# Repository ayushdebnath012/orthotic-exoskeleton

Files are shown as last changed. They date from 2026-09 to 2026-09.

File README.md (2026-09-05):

# Orthotic Exoskeleton

Design and analysis workspace for **ExoEskeleto**, a lower-limb orthotic exoskeleton. This repository brings together CAD models, manufacturing drawings, gait animations, Euler–Lagrange torque analysis, component spreadsheets, and research documents.

The current actuator-sizing study uses a **passive hip with powered knee and ankle joints**, following the updated manufacturing drawing. Research documents also explore vision-language-action (VLA) assistance and fall-risk modelling.

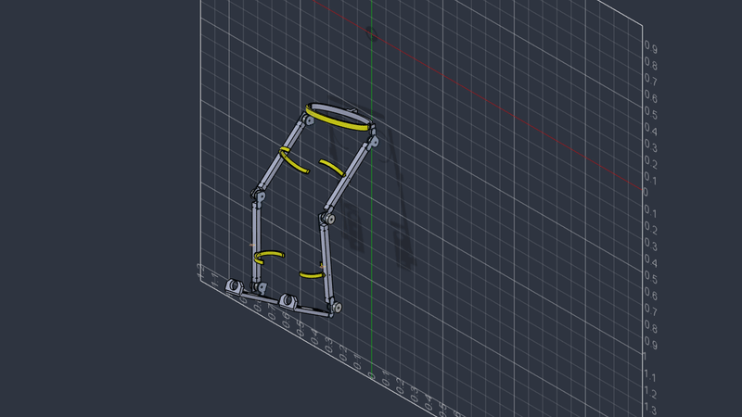
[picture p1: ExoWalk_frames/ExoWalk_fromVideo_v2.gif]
Exoskeleton gait animation


## Start here

- [Updated manufacturing drawing](ExoEskeleto_Manufacturing_Drawing%20%281%29.pdf) — hardware geometry and actuator layout.
- [Torque analysis, version 2](Motor_Torque_Analysis_ExoEskeleto_v2.md) — model, assumptions, load cases, and actuator-sizing rationale.
- [Torque analysis PDF](output/pdf/Motor_Torque_Analysis_ExoEskeleto_v2.pdf) — shareable report.
- [Bill of materials](Low_Cost_Exoskeleton_VLA_BOM_VALIDATED.xlsx) and [shopping list with screenshots](Exoskeleton_Shopping_List_with_Screenshots.xlsx) — component planning.

## Repository guide

| File or folder | Contents |
| --- | --- |
| [ExoEskeleto_final.step](ExoEskeleto_final.step) | Neutral-format assembly geometry |
| [Exoskeleton.stp.SLDPRT](Exoskeleton.stp.SLDPRT) | SolidWorks part model |
| [MOSAIC_HIP_SOLIDWORKS/](MOSAIC_HIP_SOLIDWORKS/) | Pelvic plate and hip-module part files |
| [Lagrange_Euler_Torque_Power.py](Lagrange_Euler_Torque_Power.py) | Three-link inverse dynamics, torque/power calculations, and sizing outputs |
| [ExoWalk_frames/](ExoWalk_frames/) | Joint-angle JSON data, rendered frames, GIFs, and videos |
| [exo selection animations/](exo%20selection%20animations/) | Selected walking and running animations |
| [output/torque_analysis/](output/torque_analysis/) | Saved CSV and JSON results plus torque and sizing plots |
| [output/pdf/](output/pdf/) | Version 1 and version 2 analysis reports |
| `Motor_Torque_Analysis_ExoEskeleto_v1.*` / `v2.*` | Analysis documents and available source formats |
| [ExoVLA_WM_paper.pdf](ExoVLA_WM_paper.pdf), [aegis.pdf](aegis.pdf) | Research context for assistance and control |

The version 2 report follows the updated manufacturing drawing and supersedes the earlier actuator-sizing assumptions. `ExoEskeleto_final.SLDASM` is currently an empty file; use the STEP geometry and available part files when inspecting the design.

## Run the torque analysis

Use Python 3.10 or newer with NumPy, SciPy, and Matplotlib. Run the commands from the repository root so the default gait-data path resolves correctly.

```bash
git clone https://github.com/ayushdebnath012/orthotic-exoskeleton.git
cd orthotic-exoskeleton
python3 -m pip install numpy scipy matplotlib

# Print model checks, gait results, and actuator ratings.
python3 Lagrange_Euler_Torque_Power.py

# Also generate CSV, JSON, and PNG artifacts.
python3 Lagrange_Euler_Torque_Power.py --write
```

By default, `--write` saves these files to `output/torque_analysis/`, replacing existing results with the same names:

- `euler_lagrange_gait_results.csv`
- `euler_lagrange_summary.json`
- `gait_joint_torque.png`
- `support_motor_sizing.png`

For a separate run with a different user mass:

```bash
python3 Lagrange_Euler_Torque_Power.py \
  --user-mass 70 \
  --write \
  --output-dir output/torque_analysis_70kg
```

Use `python3 Lagrange_Euler_Torque_Power.py --help` to see options for frame mass, moving-link masses, gait input, cycle time, support load, centre-of-pressure offset, and engineering factor. Matplotlib uses a non-interactive backend, so plot generation does not require a display.

## Model and sizing baseline

The analysis represents one leg as three rigid links in the sagittal plane. It evaluates a swing phase using the supplied CAD gait and a bent-knee support/sit-to-stand load case.

| Default parameter | Value |
| --- | --- |
| User mass | 80 kg |
| Frame mass | 6.49 kg |
| Thigh / shank / foot lengths | 0.400 / 0.420 / 0.260 m |
| Gait cycle | 2.4 s |
| Vertical support per leg | 0.60 × combined user and frame weight |
| Centre-of-pressure offset | 0.060 m forward of the ankle |
| Engineering factor | 1.50 |

The version 2 study selects these provisional targets **per side**, at the joint output:

| Joint | Actuation | Continuous torque target | Peak torque target | Reduction ratio |
| --- | --- | ---: | ---: | ---: |
| Hip | Passive | — | — | — |
| Knee | Powered | 60 N·m | 120 N·m | 80:1 |
| Ankle | Powered | 30 N·m | 60 N·m | 60:1 |

The passive hip still carries a reaction moment. These targets are engineering sizing results, not measured actuator performance. See the [full report](Motor_Torque_Analysis_ExoEskeleto_v2.md) for load-case calculations and motor-side torque estimates.

## Status and assumptions

This repository is a design and engineering study. The model uses estimated body-segment properties and an allocated distribution of frame mass. Measured ground-reaction-force histories, exported CAD joint zeros, motor/gearbox masses, rotor inertia, friction, backlash, and efficiency maps are not supplied. The analysis is not a human-use safety certification.

The repository includes existing research and project documents alongside the analysis. No repository-wide license has been specified.

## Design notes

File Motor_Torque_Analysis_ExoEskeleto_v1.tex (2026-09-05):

\documentclass[11pt,a4paper]{article}

\usepackage[a4paper,top=20mm,bottom=20mm,left=19mm,right=19mm,headheight=15pt]{geometry}
\usepackage[T1]{fontenc}
\usepackage{lmodern}
\usepackage{microtype}
\usepackage{graphicx}
\usepackage{booktabs}
\usepackage{tabularx}
\usepackage{array}
\usepackage{longtable}
\usepackage{amsmath}
\usepackage{enumitem}
\usepackage{xcolor}
\usepackage{fancyhdr}
\usepackage{titlesec}
\usepackage{hyperref}
\usepackage{lastpage}
\usepackage{caption}
\usepackage{float}

\definecolor{Navy}{HTML}{17324D}
\definecolor{Teal}{HTML}{167C80}
\definecolor{PaleTeal}{HTML}{E8F3F3}
\definecolor{PaleBlue}{HTML}{EDF2F7}
\definecolor{Warm}{HTML}{F6F1E8}
\definecolor{Ink}{HTML}{25313C}
\definecolor{Muted}{HTML}{647482}
\definecolor{Rule}{HTML}{CCD6DD}

\hypersetup{
  colorlinks=true,
  linkcolor=Navy,
  urlcolor=Teal,
  pdftitle={Preliminary Motor and Joint-Torque Analysis - ExoEskeleto v1},
  pdfauthor={Engineering analysis prepared from ExoEskeleto Drawing v1}
}

\color{Ink}
\setlength{\parindent}{0pt}
\setlength{\parskip}{5.5pt}
\setlist[itemize]{leftmargin=5mm,itemsep=2pt,topsep=3pt}
\setlist[enumerate]{leftmargin=6mm,itemsep=2pt,topsep=3pt}
\renewcommand{\arraystretch}{1.18}
\captionsetup{font=small,labelfont={bf,color=Navy}}

\titleformat{\section}
  {\Large\bfseries\color{Navy}}
  {\thesection}{0.65em}{}
  [\vspace{-3pt}\color{Teal}\titlerule]
\titleformat{\subsection}
  {\large\bfseries\color{Navy}}
  {\thesubsection}{0.55em}{}
\titleformat{\subsubsection}
  {\normalsize\bfseries\color{Teal}}
  {\thesubsubsection}{0.5em}{}
\titlespacing*{\section}{0pt}{13pt}{7pt}
\titlespacing*{\subsection}{0pt}{10pt}{4pt}
\titlespacing*{\subsubsection}{0pt}{8pt}{3pt}

\pagestyle{fancy}
\fancyhf{}
\fancyfoot[L]{\small\color{Muted}Preliminary engineering analysis}
\fancyfoot[R]{\small\color{Muted}Page \thepage\ of \pageref*{LastPage}}
\renewcommand{\headrulewidth}{0pt}
\renewcommand{\footrulewidth}{0pt}
\fancypagestyle{plain}{%
  \fancyhf{}
  \fancyfoot[L]{\small\color{Muted}Preliminary engineering analysis}
  \fancyfoot[R]{\small\color{Muted}Page \thepage\ of \pageref*{LastPage}}
  \renewcommand{\headrulewidth}{0pt}
  \renewcommand{\footrulewidth}{0pt}
}

\newcommand{\unit}[1]{\ensuremath{\,\mathrm{#1}}}
\newcommand{\Nm}{\unit{N\,m}}
\newcommand{\highlightbox}[2]{%
  \begingroup
  \setlength{\fboxsep}{8pt}%
  \noindent\colorbox{#1}{\parbox{\dimexpr\linewidth-2\fboxsep\relax}{#2}}%
  \endgroup
}
\newcommand{\ratingcard}[3]{%
  \begin{minipage}[t]{0.30\textwidth}
    \colorbox{PaleTeal}{\parbox[c][27mm][c]{\dimexpr\linewidth-2\fboxsep\relax}{
      \centering\color{Navy}\bfseries #1\\[2pt]
      {\Large\color{Teal}#2}\\[-1pt]
      {\scriptsize\color{Muted}#3}
    }}
  \end{minipage}%
}

\begin{document}

\begin{titlepage}
  \thispagestyle{empty}
  \vspace*{-5mm}
  {\color{Teal}\rule{\linewidth}{2.2mm}}\\[8mm]
  {\small\bfseries\color{Teal}\MakeUppercase{Preliminary engineering report}}\\[5mm]
  {\fontsize{28}{32}\selectfont\bfseries\color{Navy}
    Motor and Joint-Torque Analysis}\\[2mm]
  {\Large\color{Muted}ExoEskeleto Drawing v1}\\[4mm]
  {\color{Rule}\rule{\linewidth}{0.8pt}}

  \begin{center}
    
  \end{center}

  \vspace{-2mm}
  \begin{center}
    \ratingcard{HIP}{120--150\Nm}{peak output, each side}\hfill
    \ratingcard{KNEE}{80--110\Nm}{peak output, each side}\hfill
    \ratingcard{ANKLE}{120--150\Nm}{peak output, each side}
  \end{center}
  \vspace{5mm}

  \begin{tabularx}{\linewidth}{@{}>{\bfseries\color{Navy}}p{35mm}X@{}}
    Source drawing & \texttt{ExoEskeleto Drawing v1.pdf}, 17 sheets \\
    Drawing date & 13 July 2026 \\
    Reference user & 80 kg \\
    Report status & Preliminary sizing; not approved for human testing \\
  \end{tabularx}

  \vfill
  {\small\color{Muted}Prepared from the geometry and bill of materials supplied in the source drawing.}
\end{titlepage}

\pagenumbering{arabic}

\highlightbox{Warm}{%
  \textbf{Scope and safety limitation.} This report is a first-pass actuator-sizing study based on the drawing and explicitly stated assumptions. It is not a final design approval or safety certification. Complete CAD mass-property extraction, multibody simulation, structural FEA, brake validation, thermal/electrical analysis, and controlled bench testing are required before testing on a person.
}

\tableofcontents
\vspace{4mm}

\section{Executive summary}

The 17-sheet drawing establishes the overall exoskeleton arrangement and principal link geometry. It does not define rotary motors, gearboxes, rated joint torques, component mass properties, actuator moment arms, gait profiles, or an assistance target. The bill of materials instead identifies seven electromagnets and eleven magnetic laminations or plates.

For a reference 80 kg user and a full lower-limb support envelope, the recommended preliminary output-side ratings are shown in Table~\ref{tab:ratings}. Six powered flexion/extension joints are implied if both hip, knee, and ankle joints are actuated.

Applying the Lagrange-Euler equation to the report's three-link reference model gives, for the stated horizontal dynamic example, $60.21\Nm$ and 90.31 W at the hip, $17.99\Nm$ and 35.98 W at the knee, and $2.54\Nm$ and 6.35 W at the ankle. These are unfactored swing-phase values for human-segment mass only; they exclude exoskeleton mass and ground-reaction force.

\begin{table}[H]
\centering
\caption{Preliminary joint-output design envelope, each side.}
\label{tab:ratings}
\small
\begin{tabularx}{\linewidth}{@{}>{\raggedright\arraybackslash}p{32mm}
  >{\centering\arraybackslash}p{24mm}
  >{\centering\arraybackslash}p{24mm}
  >{\centering\arraybackslash}p{19mm}X@{}}
\toprule
\textbf{Joint} & \textbf{Continuous torque} & \textbf{Peak torque} & \textbf{Output speed} & \textbf{Approximate actuator class} \\
\midrule
Hip flexion/extension & 45--60\Nm & 120--150\Nm & 0--3 rad/s & 300--500 W BLDC with low-backlash reducer \\
Knee flexion/extension & 30--45\Nm & 80--110\Nm & 0--4 rad/s & 250--400 W BLDC with low-backlash reducer \\
Ankle plantar/dorsiflexion & 45--60\Nm & 120--150\Nm & 0--5 rad/s & 350--600 W BLDC with reducer or remote transmission \\
\bottomrule
\end{tabularx}
\end{table}

\highlightbox{PaleTeal}{%
  \textbf{Primary design finding.} The electromagnets should be treated as auxiliary locks, clutches, or mode-selection devices unless their force-versus-gap and friction performance are demonstrated. They should not be assumed to replace torque-controlled rotary actuators or certified fail-safe brakes.
}

\section{Drawing basis and observed geometry}

\subsection{Information established by the drawing}

\begin{itemize}
  \item Overall envelope: approximately 1009 mm high, 1009 mm long, and 662 mm wide (sheet 2).
  \item Principal long members: approximately 400--420 mm on the detail sheets.
  \item Several circular joint/interface details: approximately 50 mm outside diameter with 10 mm bores.
  \item Bill of materials: seven \texttt{ELECTROIMAN} units and eleven magnetic laminations or plates.
  \item Listed structural parts are identified as steel.
  \item The assembly appears to comprise bilateral lower-limb links connected to a waist ring and foot/boot interfaces.
\end{itemize}

\subsection{Information not supplied}

The drawing does not provide maximum user mass, payload, part masses, centres of mass, gait cycle, required assistance percentage, motor torque-speed curves, gearbox ratios or efficiencies, bearing friction, joint range, structural steel grade, weld specifications, or electromagnet force data. These omissions prevent an exact CAD-derived actuator calculation.

\section{Reference design case}

The assumptions in Table~\ref{tab:assumptions} provide a transparent first-pass sizing case. Segment masses are anthropometric approximations and exclude exoskeleton hardware.

\begin{table}[H]
\centering
\caption{Reference assumptions used in the calculations.}
\label{tab:assumptions}
\begin{tabularx}{0.88\linewidth}{@{}X>{\raggedleft\arraybackslash}p{59mm}@{}}
\toprule
\textbf{Parameter} & \textbf{Assumption} \\
\midrule
User mass & 80 kg \\
Thigh length & 0.42 m \\
Shank length & 0.40 m \\
Foot COM distance from ankle & 0.13 m \\
One thigh mass & 10.0\% body mass = 8.00 kg \\
One shank mass & 4.65\% body mass = 3.72 kg \\
One foot mass & 1.45\% body mass = 1.16 kg \\
Thigh and shank COM location & 43.3\% of segment length from proximal joint \\
Gravity, $g$ & $9.81\unit{m/s^2}$ \\
Dynamic multiplier & 2.0 \\
Engineering factor after dynamics & 1.5 \\
\bottomrule
\end{tabularx}
\end{table}

The dynamic and engineering factors are included to establish an actuator selection envelope. Final load cases must instead use measured or simulated joint torque histories and include every moving exoskeleton component.

\section{Static gravity calculations}

For a point mass, the gravity moment about a joint is
\begin{equation}
  T = m g r,
\end{equation}
where $r$ is the horizontal distance from the joint axis. Gravity torque is largest when the segment is approximately horizontal.

\subsection{Hip: one leg held horizontal}

\begin{align}
T_{\mathrm{hip}} = g\big[&m_t(0.433L_t)
  + m_s(L_t+0.433L_s) \notag\\
  &+m_f(L_t+L_s+r_f)\big].
\end{align}

For the 80 kg reference user,
\begin{equation}
  \boxed{T_{\mathrm{hip}} = 46.7\Nm}
\end{equation}
for limb self-weight alone. This does not include the exoskeleton links, actuator masses, payload, or ground-reaction effects.

\subsection{Knee: shank and foot held horizontal}

\begin{equation}
T_{\mathrm{knee}} = g\left[m_s(0.433L_s)+m_f(L_s+r_f)\right],
\end{equation}
giving
\begin{equation}
  \boxed{T_{\mathrm{knee}} = 12.3\Nm}.
\end{equation}

\subsection{Ankle: ground-reaction load governs}

Foot self-weight produces only about $1.5\Nm$. This is not the governing ankle case. During standing and walking, ground-reaction force acts at a horizontal offset from the ankle. For the complete 80 kg body load and a 50--120 mm centre-of-pressure offset,
\begin{align}
T_{\mathrm{ankle}}
 &= (80)(9.81)(0.05\text{ to }0.12) \\
 &= \boxed{39\text{ to }94\Nm}.
\end{align}

In symmetric double support, each side may carry approximately half the load. In single support, one side can approach the full value and can exceed it dynamically.

\section{Lagrange-Euler torque and power calculation}

\subsection{Three-link planar model}

Let
\begin{equation}
  \mathbf q = [q_1\ q_2\ q_3]^T
\end{equation}
contain the relative hip, knee, and ankle angles. The pelvis is treated as a fixed base; $q_1$ is measured from the global horizontal, while $q_2$ and $q_3$ are relative angles. Positive rotation is counter-clockwise.

For the three moving segments, the kinetic and potential energies are
\begin{align}
K &= \frac{1}{2}\sum_{i=1}^{3}
  \left(m_i\dot{\mathbf r}_i^T\dot{\mathbf r}_i
  + I_i\omega_i^2\right),\\
V &= \sum_{i=1}^{3}m_i g y_i,
\end{align}
and the Lagrangian is $\mathcal L=K-V$. Applying the requested equation at each joint,
\begin{equation}
  \tau_i=\frac{d}{dt}\left(\frac{\partial\mathcal L}
  {\partial\dot q_i}\right)-\frac{\partial\mathcal L}{\partial q_i},
\end{equation}
gives the manipulator form
\begin{equation}
\boxed{\boldsymbol\tau_{\mathrm{act}}
=\mathbf M(\mathbf q)\ddot{\mathbf q}
+\mathbf C(\mathbf q,\dot{\mathbf q})\dot{\mathbf q}
+\mathbf G(\mathbf q)-\mathbf J_f^T\mathbf F_{\mathrm{ext}}.}
\end{equation}

The final term is essential in stance: $\mathbf F_{\mathrm{ext}}$ is the measured ground-reaction force at the foot and $\mathbf J_f$ is the foot Jacobian. It is set to zero in the numerical swing example because no force history is supplied.

Segment inertias are estimated using $I_i=m_i(k_iL_i)^2$. The radius-of-gyration fractions for thigh, shank, and foot are 0.323, 0.302, and 0.475, respectively. The calculation includes human segment mass only.

\subsection{Numerical input state}

The selected instant is deliberately explicit so that the result can be reproduced or replaced with measured data.

\begin{table}[H]
\centering
\caption{State used for the illustrative Lagrange-Euler calculation.}
\label{tab:lagrange-input}
\begin{tabular}{@{}lccc@{}}
\toprule
\textbf{Quantity} & \textbf{Hip} & \textbf{Knee} & \textbf{Ankle} \\
\midrule
$q_i$ & $0^\circ$ & $0^\circ$ & $0^\circ$ \\
$\dot q_i$ & 1.5 rad/s & 2.0 rad/s & 2.5 rad/s \\
$\ddot q_i$ & $3.0\unit{rad/s^2}$ & $4.0\unit{rad/s^2}$ & $5.0\unit{rad/s^2}$ \\
External foot force & \multicolumn{3}{c}{$\mathbf F_{\mathrm{ext}}=[0\ 0]^T\unit{N}$} \\
\bottomrule
\end{tabular}
\end{table}

At this collinear horizontal configuration,
\begin{equation}
\mathbf M=
\begin{bmatrix}
2.8397 & 1.0382 & 0.1610\\
1.0382 & 0.5094 & 0.0976\\
0.1610 & 0.0976 & 0.0373
\end{bmatrix}\unit{kg\,m^2},
\end{equation}
\begin{equation}
\mathbf G=
\begin{bmatrix}46.7308\\12.3518\\1.4793\end{bmatrix}\Nm,
\qquad
\mathbf C\dot{\mathbf q}=\mathbf 0.
\end{equation}

The Coriolis/centrifugal vector is zero at this particular collinear state because the required sine coupling terms vanish; it is generally non-zero at other postures.

\subsection{Calculated torque and joint power}

Instantaneous joint mechanical power is
\begin{equation}
  \boxed{P_i=\tau_i\dot q_i.}
\end{equation}
Positive power drives the motion; negative power indicates braking or potential regeneration.

\begin{table}[H]
\centering
\caption{Unfactored dynamic result for the state in Table~\ref{tab:lagrange-input}.}
\label{tab:lagrange-result}
\small
\begin{tabular}{@{}lrrrr@{}}
\toprule
\textbf{Joint} & \textbf{Inertial} & \textbf{Gravity} & \textbf{Total torque} & \textbf{Joint power} \\
& \textbf{(N m)} & \textbf{(N m)} & \textbf{(N m)} & \textbf{(W)} \\
\midrule
Hip & 13.477 & 46.731 & \textbf{60.208} & \textbf{90.311} \\
Knee & 5.640 & 12.352 & \textbf{17.992} & \textbf{35.985} \\
Ankle & 1.060 & 1.479 & \textbf{2.539} & \textbf{6.348} \\
\midrule
Total & & & & \textbf{132.644} \\
\bottomrule
\end{tabular}
\end{table}

For example, the first-joint calculation is
\begin{align}
\tau_1 &=
  2.8397(3)+1.0382(4)+0.1610(5)+46.7308 \\
  &=\boxed{60.208\Nm},\\
P_1 &= \tau_1\dot q_1
  =60.208(1.5)=\boxed{90.311\unit{W}}.
\end{align}

If a separate 1.5 engineering factor is applied after this trajectory calculation, the resulting provisional values are 90.31, 26.99, and $3.81\Nm$ for hip, knee, and ankle. The ankle value remains unsuitable for stance sizing because the ground-reaction term is absent.

\subsection{Illustrative gearbox mapping}

Using 80:1 hip and knee reducers, a 60:1 ankle reducer, and 75\% gearbox efficiency gives Table~\ref{tab:motor-map}. Shaft power is joint power divided by gearbox efficiency; electrical input will be higher again after motor and drive losses.

\begin{table}[H]
\centering
\caption{Motor-side result for the illustrative swing state.}
\label{tab:motor-map}
\begin{tabular}{@{}lrrrr@{}}
\toprule
\textbf{Joint} & \textbf{Ratio} & \textbf{Motor torque} & \textbf{Motor speed} & \textbf{Shaft power} \\
& & \textbf{(N m)} & \textbf{(rpm)} & \textbf{(W)} \\
\midrule
Hip & 80:1 & 1.003 & 1146 & 120.4 \\
Knee & 80:1 & 0.300 & 1528 & 48.0 \\
Ankle & 60:1 & 0.056 & 1432 & 8.5 \\
\bottomrule
\end{tabular}
\end{table}

As a conservative instantaneous envelope, multiplying the preliminary peak torque and maximum speed in Table~\ref{tab:ratings} gives 450 W at the hip, 440 W at the knee, and 750 W at the ankle. Torque and speed peaks normally occur at different times, so these products are upper bounds rather than continuous motor ratings. Final continuous power must be based on cycle RMS torque, measured speed histories, gearbox efficiency maps, and thermal limits.

\section{Motor and transmission sizing}

\subsection{Torque and ratio relationship}

For gearbox ratio $N$ and transmission efficiency $\eta$, required motor torque is
\begin{equation}
  T_{\mathrm{motor}}=\frac{T_{\mathrm{joint}}}{N\eta}.
\end{equation}

For a $120\Nm$ peak joint, an 80:1 ratio, and 75\% efficiency,
\begin{equation}
  T_{\mathrm{motor,peak}}
  =\frac{120}{80(0.75)}
  =\boxed{2.0\Nm}.
\end{equation}

At 60:1 and 80\% efficiency, the same joint requires $2.5\Nm$ motor peak torque. A reduction range near 50:1--100:1 is a reasonable starting point, but the final ratio must satisfy joint torque, joint speed, thermal duty, backlash, and backdrivability requirements simultaneously.

\subsection{Recommended architecture}

\begin{itemize}
  \item 48 V BLDC or PMSM actuators to limit current and cable mass.
  \item Absolute joint encoder plus motor encoder.
  \item Low-backlash harmonic, cycloidal, or well-supported planetary reducer.
  \item Torque sensing through a strain element or series-elastic element.
  \item Normally engaged mechanical brake at each load-bearing joint.
  \item Mechanical hard stops independent of software.
\end{itemize}

High reduction improves torque density but reduces backdrivability and increases reflected inertia. Torque sensing and mechanical compliance are strongly preferred for a wearable device. Distal motor mass also increases swing torque; proximal knee actuation and remote ankle transmission should be evaluated.

\subsection{Scaling and partial assistance}

For a user mass $M$ different from 80 kg, a first approximation is
\begin{equation}
T_{\mathrm{new}} = T_{\mathrm{table}}\left(\frac{M}{80}\right)
+T_{\mathrm{exo+payload}}.
\end{equation}

For partial assistance, multiply the biological joint-torque target by the desired assistance fraction. For example, 40\% assistance at a $150\Nm$ ankle peak requires approximately $60\Nm$ actuator output before transmission losses and friction are added.

\section{Electromagnet feasibility check}

If an electromagnet at a nominal 50 mm diameter interface is expected to resist joint torque through friction at an effective radius of approximately 25 mm, the required tangential force is
\begin{equation}
  F_t=\frac{T}{r}.
\end{equation}

\begin{table}[H]
\centering
\caption{Tangential force implied at a 25 mm effective radius.}
\begin{tabular}{@{}rr@{}}
\toprule
\textbf{Joint torque} & \textbf{Tangential force} \\
\midrule
$60\Nm$ & 2400 N \\
$120\Nm$ & 4800 N \\
$150\Nm$ & 6000 N \\
\bottomrule
\end{tabular}
\end{table}

Friction torque is $T=\mu F_n r$. With a nominal dry friction coefficient of 0.3, holding $120\Nm$ at a 25 mm radius requires
\begin{equation}
F_n=\frac{120}{0.3(0.025)}=\boxed{16{,}000\unit{N}}
\end{equation}
of magnetic normal force. Air gaps, surface contamination, coil heating, and loss of electrical power further reduce dependable holding capacity.

\highlightbox{Warm}{%
  \textbf{Design implication.} Do not use the drawn electromagnets as the sole load-bearing joint brakes without a demonstrated force/torque test. If used for locking or mode selection, add a mechanically positive, normally locked feature so that loss of power cannot release the user.
}

\section{Structural and integration observations}

\begin{itemize}
  \item Several details show 10 mm bores. A pin at this interface requires combined shear, bearing, bending, fatigue, and retention analysis; bore diameter alone is insufficient.
  \item Long 400--420 mm links and offset cuffs introduce bending and torsion in addition to in-plane joint torque.
  \item The BOM states steel but does not provide grade, complete thickness data, heat treatment, weld details, or allowable stress.
  \item Joint axes must align with the user's anatomical hip, knee, and ankle axes. Misalignment can create harmful cuff forces even when motor torque is within its limit.
  \item Knee motors should preferably be placed proximally. The ankle may benefit from cable, Bowden, belt, or linkage transmission to reduce distal mass.
  \item Motor torque must not be the only protection against collapse during power loss.
\end{itemize}

\clearpage
\section{Data required for final sizing}

\begin{enumerate}
  \item Maximum user mass and carried payload.
  \item Intended function: rehabilitation assistance, full weight support, sit-to-stand, walking, or static locking.
  \item Required degrees of freedom, angular limits, and mechanical stop positions.
  \item Target gait speed and joint angle, velocity, and acceleration profiles versus time.
  \item CAD mass and centre of mass for each link, motor, gearbox, battery, and attachment.
  \item Electromagnet model, force-versus-gap curve, coil power, friction material, effective radius, and fail-safe behaviour.
  \item Gearbox ratio, efficiency, backlash, rated output moment, shock rating, and life.
  \item Ground-reaction-force cases and required assistance percentage.
\end{enumerate}

\section{Conclusion}

For an 80 kg reference user and full lower-limb support, size each side initially for $120$--$150\Nm$ peak at the hip, $80$--$110\Nm$ peak at the knee, and $120$--$150\Nm$ peak at the ankle, with the continuous ratings in Table~\ref{tab:ratings}. These are output-side design-envelope values, not motor-shaft values.

The seven electromagnets identified in the drawing are best treated as auxiliary locks or clutches. They are not substitutes for torque-controlled rotary motors or validated fail-safe brakes. Human testing should not begin until the missing design inputs are resolved and the system has passed simulation, structural verification, brake testing, thermal analysis, electrical safety review, and controlled bench trials.

\vfill
\highlightbox{PaleBlue}{%
  \textbf{Next engineering release.} Replace the reference anthropometric model with CAD mass properties and measured motion/load cases, then issue a joint-by-joint motor, reducer, brake, bearing, pin, and controller specification.
}

\end{document}

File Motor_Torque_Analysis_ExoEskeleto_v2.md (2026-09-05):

# Euler-Lagrange Joint and Motor Torque Analysis

## ExoEskeleto lower-limb exoskeleton - knee-dominant actuator sizing

**Reference user:** 80 kg  
**Frame:** 6.49 kg, Aluminium 6061-T6  
**Actuation used for sizing:** passive hip, powered knee and ankle  
**Analysis date:** 28 July 2026  
**Status:** engineering sizing study; not a human-use safety certification

---

## 1. Result

The updated manufacturing drawing makes the hip a passive pivot and locates
actuation at the knee and ankle. The motor-torque hierarchy is therefore:

| Joint, each side | Motor status | Continuous output target | Peak output target | Provisional reducer |
|---|---|---:|---:|---:|
| Hip | Passive | 0 N m | 0 N m | None |
| **Knee** | **Powered - highest** | **60 N m** | **120 N m** | **80:1** |
| Ankle | Powered | 30 N m | 60 N m | 60:1 |

The governing knee-dominant case is a bent-knee support/sit-to-stand posture.
Euler-Lagrange inverse dynamics gives:

- Passive hip reaction: -11.03 N m
- **Knee actuator torque: +70.74 N m**
- Ankle actuator torque: -28.30 N m

After a 1.5 engineering factor, the absolute requirements are 16.55, 106.10,
and 42.45 N m. Rounding upward in 20 N m increments gives a 120 N m knee
target and 60 N m ankle target.

The knee is not made highest by changing the equations. It is highest because
the selected design posture places the ground-reaction-force line about
150 mm behind the knee but only 60 mm ahead of the ankle. The passive hip has
no motor even though it still carries a reaction moment.

---

## 2. Workspace evidence and precedence

The following source hierarchy was applied.

### Authoritative hardware input

`ExoEskeleto_Manufacturing_Drawing (1).pdf`, 18 pages, dated 26-07-2026:

- Aluminium 6061-T6 construction.
- Total frame mass: 6.49 kg, excluding motors and hardware.
- Thigh rod `Ac40`: 400 mm.
- Shank rod `Ac30`: 420 mm.
- "Knee & ankle joints house the actuators; hips are passive pivots."

This drawing supersedes the earlier `ExoEskeleto Drawing v1.pdf` where the BOM
listed steel and seven electromagnets but supplied no frame mass or actuator
architecture.

### Geometry and motion sources

- `ExoEskeleto_final.step`: assembly geometry and material-density entities,
  but no directly usable exported per-part mass, centre of mass, or inertia
  table.
- `ExoEskeleto_final.SLDASM`: zero-byte file; it contains no usable assembly
  information.
- `Exoskeleton.stp.SLDPRT`: large SolidWorks part container; no neutral
  per-part mass-properties report is supplied.
- `ExoWalk_frames/blended.json`: 60-frame bilateral joint-angle history.
- `ExoWalk_frames/ExoWalk_fromVideo_v2.gif`: 60 frames at 40 ms/frame, giving
  a 2.4 s cycle.
- Frame PNGs, GIFs, MP4s, and JPG renders confirm a bilateral, sagittal
  hip-knee-ankle linkage but do not define joint zeros or force histories.

### Context only

`aegis.pdf`, `ExoVLA_WM_paper.pdf`, and the ExoVLA-WM proposal describe
assistance control, safety supervision, and fall-risk modelling. They do not
provide this mechanism's motor torque, gearbox, mass-property, or
ground-reaction-force data. The M.Tech allotment form establishes the project
area as robotics but contains no dynamics input.

---

## 3. Euler-Lagrange model

One sagittal-plane leg is represented by three rigid links:

- `q1`: thigh absolute angle from the global horizontal.
- `q2`: knee angle relative to the thigh.
- `q3`: ankle/foot angle relative to the shank.

The absolute link angles are:

`phi1 = q1`

`phi2 = q1 + q2`

`phi3 = q1 + q2 + q3`

For component `a` on link `i`, its kinetic and potential energies are:

`T_a = 0.5 m_a v_a^T v_a + 0.5 I_a omega_i^2`

`V_a = m_a g y_a`

The system Lagrangian is:

`L = T - V`

For each generalized coordinate:

`d/dt(partial L / partial qdot_i) - partial L / partial q_i
 = tau_i + [J_COP(q)^T F]_i`

Rearranging into inverse-dynamics form gives the actuator/reaction demand:

`tau_req = M(q) qdd + C(q,qdot) qdot + G(q) - J_COP(q)^T F`

where:

- `M(q)` is the symmetric positive-definite mass matrix.
- `C(q,qdot) qdot` contains Coriolis and centrifugal terms.
- `G(q)` is the gravity vector.
- `J_COP^T F` maps the foot ground-reaction force into joint coordinates.

The hip entry in `tau_req` is reported as a passive reaction. The commanded
motor vector is:

`tau_motor_output = [0, tau_knee, tau_ankle]^T`

### Numerical validation

The implemented model passed:

| Check | Result |
|---|---:|
| Maximum mass-matrix asymmetry | 0.000e+00 |
| Minimum tested eigenvalue of `M` | 2.132e-02 kg m^2 |
| Coriolis term at zero velocity | 0.000e+00 N m |
| Euler-Lagrange power-identity error | 3.553e-15 W |

---

## 4. Parameters

### Human segments, one leg

The nominal user mass is 80 kg.

| Segment | Mass fraction | Mass | COM from proximal joint | Radius-of-gyration fraction |
|---|---:|---:|---:|---:|
| Thigh | 10.00% | 8.00 kg | 0.433 x 0.400 = 0.1732 m | 0.323 |
| Shank | 4.65% | 3.72 kg | 0.433 x 0.420 = 0.1819 m | 0.302 |
| Foot | 1.45% | 1.16 kg | 0.500 x 0.260 = 0.1300 m | 0.475 |

### Exoskeleton moving-link allocation

The 6.49 kg total is known, but the drawing does not give per-part mass
properties. The documented nominal allocation is:

| Moving exoskeleton group, one leg | Assigned mass | COM model |
|---|---:|---|
| Thigh link and local plates | 0.75 kg | 50% of link |
| Shank link and local plates | 0.90 kg | 50% of link |
| Foot link and local plates | 0.60 kg | 50% of link |
| **Moving subtotal, two legs** | **4.50 kg** | |
| Fixed pelvis/waist remainder | **1.99 kg** | Not in moving-link kinetic energy |
| **Total** | **6.49 kg** | |

Motor and gearbox mass is excluded because no model or mass is specified. A
final CAD mass-property export should replace this allocation.

---

## 5. CAD gait swing result

The 60-frame `blended.json` sequence was evaluated over the measured 2.4 s GIF
cycle. The first frame was used as the only available joint-zero calibration:
vertical thigh, extended knee, horizontal foot. The stance force was set to
zero, so this is a swing/inertial result only.

| Side | Joint | Peak absolute torque | RMS torque | Peak speed | Peak absolute power |
|---|---|---:|---:|---:|---:|
| Left | Passive hip reaction | 34.67 N m | 15.21 N m | 1.679 rad/s | 39.39 W |
| Left | **Knee motor** | **10.18 N m** | **6.24 N m** | **2.007 rad/s** | **17.84 W** |
| Left | Ankle motor | 3.67 N m | 2.36 N m | 1.157 rad/s | 3.54 W |
| Right | Passive hip reaction | 43.05 N m | 20.97 N m | 2.186 rad/s | 55.26 W |
| Right | **Knee motor** | **14.35 N m** | **7.22 N m** | **1.512 rad/s** | **16.70 W** |
| Right | Ankle motor | 3.20 N m | 2.19 N m | 0.965 rad/s | 2.41 W |

The knee is the highest powered joint in the supplied swing motion. The larger
hip result is a passive structural/pelvis reaction, not motor torque.

The animation is not a measured human gait dataset. Its joint naming, zero
offsets, and axis signs are not exported, and it contains no force-plate data.
It is useful for a first dynamic check, not final actuator certification.

---

## 6. Governing knee-dominant support case

The design posture uses:

- `q = [-60, -60, 120] deg`, giving a horizontal foot.
- Vertical support per leg:
  `F_y = 0.60 (80 + 6.49) 9.81 = 509.08 N`.
- This equals 1.2 combined body/frame weight split between two feet.
- Centre of pressure: 60 mm forward of the ankle.
- Quasi-static peak: `qdot = 0`, `qdd = 0`.

At this posture:

`M(q) =`

`[[2.668720, 0.867689, 0.048529],`

` [0.867689, 0.500985, 0.002769],`

` [0.048529, 0.002769, 0.050817]] kg m^2`

The torque decomposition is:

| Joint | `M qdd` | `C qdot` | `G` | `J_COP^T F` | `tau_req` | `1.5 abs(tau_req)` |
|---|---:|---:|---:|---:|---:|---:|
| Passive hip reaction | 0 | 0 | +14.423 | +25.454 | -11.031 | 16.546 N m |
| **Knee motor** | **0** | **0** | **-5.627** | **-76.362** | **+70.735** | **106.103 N m** |
| Ankle motor | 0 | 0 | +2.245 | +30.545 | -28.300 | 42.450 N m |

The knee ground-force moment is the governing term. The result directly
supports a knee-highest actuator rating for support and sit-to-stand.

---

## 7. Motor and gearbox mapping

For reduction ratio `N` and gearbox efficiency `eta`:

`T_motor = T_output / (N eta)`

`rpm_motor = qdot_joint N 60 / (2 pi)`

| Joint, each side | Output continuous | Output peak | Ratio | Efficiency | Motor continuous | Motor peak | Motor rpm at measured gait peak |
|---|---:|---:|---:|---:|---:|---:|---:|
| **Knee** | **60 N m** | **120 N m** | **80:1** | **0.75** | **1.000 N m** | **2.000 N m** | **1533 rpm** |
| Ankle | 30 N m | 60 N m | 60:1 | 0.75 | 0.667 N m | 1.333 N m | 663 rpm |

Provisional motor classes:

- Knee: 48 V BLDC/PMSM, approximately 300-400 W, with a reducer rated for at
  least 120 N m peak output and the required shock/fatigue life.
- Ankle: 48 V BLDC/PMSM, approximately 150-250 W, with a reducer rated for at
  least 60 N m peak output.

These power classes are provisional because the supplied files contain no
measured loaded joint-speed history or duty cycle. Select against the motor's
thermal continuous-torque curve, not stall torque.

The passive hip still needs bearings, stops, and structure sized for reaction
torque. The maximum swing reaction here is 43.05 N m; applying 1.5 gives
64.58 N m before shock/fatigue allowance.

---

## 8. Sensitivity and limits of the knee-highest condition

### User mass sensitivity

The same bent-knee case gives:

| User mass | Raw knee torque | Factored knee torque | Raw ankle torque | Factored ankle torque |
|---:|---:|---:|---:|---:|
| 60 kg | 54.14 N m | 81.20 N m | 21.61 N m | 32.41 N m |
| 70 kg | 62.44 N m | 93.65 N m | 24.95 N m | 37.43 N m |
| **80 kg** | **70.74 N m** | **106.10 N m** | **28.30 N m** | **42.45 N m** |
| 90 kg | 79.04 N m | 118.55 N m | 31.65 N m | 47.47 N m |
| 100 kg | 87.34 N m | 131.00 N m | 34.99 N m | 52.49 N m |

The 120 N m knee target covers this stated case through approximately 90 kg.
For a 100 kg user, use at least a 140 N m knee output target under the same
assumptions.

### Centre-of-pressure sensitivity

| COP forward of ankle | Absolute hip reaction | Absolute knee torque | Absolute ankle torque |
|---:|---:|---:|---:|
| 20 mm | 9.33 N m | 91.10 N m | 7.94 N m |
| 40 mm | 0.85 N m | 80.92 N m | 18.12 N m |
| **60 mm** | **11.03 N m** | **70.74 N m** | **28.30 N m** |
| 80 mm | 21.21 N m | 60.55 N m | 38.48 N m |
| 100 mm | 31.39 N m | 50.37 N m | 48.66 N m |
| 120 mm | 41.58 N m | 40.19 N m | 58.85 N m |

The knee is highest for the selected support/sit-to-stand loading. During
far-forward toe-off, ankle torque can physically exceed knee torque. If the
device must provide full powered push-off, the ankle must be re-sized from
measured force-plate and COP histories; it is not correct to suppress that
load merely to preserve a desired ranking.

---

## 9. Required data before hardware release

1. Maximum user mass, carried payload, and required assistance percentage.
2. Native CAD mass, COM, and inertia for every moving part, motor, and gearbox.
3. Exact motor and reducer models, efficiency maps, backlash, reflected
   inertia, output-bearing moment rating, and thermal curves.
4. Calibrated joint zeros and axis signs for every CAD `Revolute` channel.
5. Loaded joint angle, velocity, and acceleration versus time.
6. Synchronized ground-reaction force and COP trajectories.
7. Friction, cable/gear preload, cuff forces, hard-stop loads, and emergency
   braking loads.
8. Bench verification with an instrumented dummy load before any human test.

## Conclusion

For the current 80 kg reference case and the actuator architecture stated in
the updated manufacturing drawing, use **120 N m peak / 60 N m continuous at
each knee** and **60 N m peak / 30 N m continuous at each ankle**. The hip is
passive and has zero motor torque, although its structure must carry reaction
loads. This gives the requested and physically justified ordering:

**knee motor torque > ankle motor torque > hip motor torque (zero).**

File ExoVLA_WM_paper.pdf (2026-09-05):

# ExoVLA-WM: A Safety-Shielded Vision-Language-Action and World-Model Framework for Personalized Lower-Limb Exoskeleton Control

Ayush Debnath
Department of Mechanical Engineering Indian Institute of Technology Kharagpur Kharagpur, India
ayush.d@kgpian.iitkgp.ac.in

Abstract—Lower-limb exoskeletons must infer user intent, understand terrain, coordinate multiple powered joints, and remain safe under uncertainty. Existing systems typically separate locomotion-mode recognition from low-level control and operate over a fixed set of terrains. In parallel, vision-language-action (VLA) models have demonstrated broad semantic reasoning and cross-task transfer in manipulation, but their direct use for a human-worn robot is unsafe and mismatched to the dynamics, sensing, and action spaces of gait assistance. This paper proposes ExoVLA-WM, a hierarchical architecture that adapts a pretrained VLA to multimodal exoskeleton observations while restricting it to high-level locomotion decisions and bounded residual assistance. A predictive latent world model evaluates candidate action chunks before execution, and a deterministic safety shield enforces joint, torque, contact, stability, latency, and uncertainty constraints. The framework combines waist-mounted RGB-D perception, proprioception, foot-contact sensing, language commands, a gait-state estimator, an exoskeleton-specific action head, model-predictive risk scoring, and a real-time impedance controller. We specify the hardware layout, data format, training pipeline, simulation-to-hardware curriculum, safety mechanisms, human-in-the-loop personalization procedure, and a staged experimental protocol. Because no physical experiments have yet been completed, this manuscript is intentionally presented as a pre-experimental systems paper: it states testable hypotheses, baselines, ablations, and result templates without fabricating empirical outcomes.
Index Terms—vision-language-action models, world models, lower-limb exoskeleton, wearable robotics, computer vision, safe learning, human-in-the-loop optimization, locomotion intent
I. INTRODUCTION

Powered lower-limb exoskeletons couple a robot directly to the human body. A controller must therefore solve several problems at once: infer what the wearer intends to do, perceive the walking environment before contact, generate coordinated bilateral motion, adapt assistance to the individual, and maintain safety when perception or learning fails. Classical exoskeleton control is often hierarchical, with locomotion recognition and finite-state logic above trajectory, impedance, or torque control [1]. Such structures are interpretable and compatible with real-time guarantees, but they are commonly limited to predefined activities and require substantial tuning across users and terrains.
Computer vision can improve predictive terrain awareness. Environment classifiers have been developed for robotic prostheses and exoskeletons [2], while Exosense demonstrated visualinertial mapping and terrain reconstruction on an exoskeleton platform [3]. However, terrain labels alone do not provide language grounding, open-vocabulary goal understanding, or a unified representation of semantic context, body state, and action.
VLA models such as RT-2 [4], OpenVLA [5], and π0 [6] map visual and language inputs to robot actions. OpenVLA was pretrained on large-scale, cross-embodiment manipulation data [7], and optimized adaptation recipes have introduced continuous action heads and action chunking [8]. These models are attractive because an exoskeleton user or therapist could issue commands such as “walk to the chair,” “climb these stairs slowly,” or “give more support on the left.” Yet existing VLA action spaces are designed primarily for manipulators, and an unconstrained model must not command motor voltages or unrestricted joint torques on a wearable robot.
We propose ExoVLA-WM, illustrated in Fig. 1. The core design principle is strict separation of responsibilities:
- the VLA interprets scene, language, and body context and outputs a restricted locomotion command;
- a learned world model predicts future body, contact, and risk variables for candidate command chunks;
- a deterministic safety layer rejects or projects unsafe commands;
- a verified real-time controller executes safe references and maintains a fallback behavior independently of the VLA.

The proposed contributions are:

1) an exoskeleton-specific multimodal VLA observation and action interface;
2) a predictive world-model layer for counterfactual gait-risk evaluation;

3) a safety shield combining state-machine logic, uncertainty gating, hard limits, and control-barrier-function constraints;
4) a staged data-collection and training protocol that starts with passive sensing and expert control before any learned residual is enabled;
5) a personalization method that optimizes assistance while preserving safety envelopes; and
6) a complete experimental design with baselines, ablations, metrics, and non-fabricated result templates.

II. RELATED WORK

A. Lower-Limb Exoskeleton Control
Lower-limb exoskeleton controllers are commonly organized into high-, mid-, and low-level layers [1]. High-level modules estimate intent or select an activity; mid-level modules produce joint references or assistance profiles; low-level modules regulate position, velocity, torque, or impedance. Locomotion recognition has used inertial sensing, EMG, force sensing, and multimodal fusion. Subject-adaptive classifiers [9] and neural models using a shank-mounted IMU [10] show that continuous gait phase and terrain-related variables can be estimated with lightweight sensors. More recent on-sensor approaches further motivate a separate low-power fallback recognizer [11]. Data-driven exoskeleton control is also emerging. Vianello et al. infer locomotion features and map therapist edits to desired posture and stiffness [12]. Simulation-trained policies can reduce the cost and risk of hardware data collection [13]. These works motivate learning-rich controllers, but they do not directly address open-vocabulary language grounding or the use of large pretrained VLA representations.
B. Visual Environment Understanding
Vision can identify terrain before physical contact and therefore reduce delayed controller transitions. Deep convolutional models have been studied for environment classification [2]. Exosense extends perception from classification to visualinertial mapping and terrain reconstruction [3]. Our framework uses these ideas as a perception substrate, but combines geometry with language, proprioception, predictive action evaluation, and explicit uncertainty handling.
C. Vision-Language-Action Models
RT-2 introduced action tokenization within a vision-language model [4]. Open X-Embodiment consolidated heterogeneous robot datasets [7]; OpenVLA used such data to create an open, adaptable VLA [5]. OpenVLA-OFT showed that continuous action representations, parallel decoding, and action chunking can substantially improve adaptation speed and success [8]. Flow-based policies such as π0 provide another route to continuous action generation [6]. Diffusion Policy [14] and ACT [15] are strong from-scratch baselines for sequence-level visuomotor control.
The proposed exoskeleton application differs in three important respects. First, the robot is physically attached to a human, so safety requirements are more stringent. Second, task success is not sufficient; interaction force, comfort, stability, assistance timing, and user adaptation are also outcomes. Third, locomotion control requires deterministic high-rate loops that cannot depend on a large VLA inference stack.
D. World Models, Safety and Failure Detection
World models predict future outcomes of candidate actions and support planning in latent space. DreamerV3 [16] and TD-MPC2 [17] demonstrate scalable model-based learning and latent trajectory optimization. We adapt the concept to short-horizon prediction of gait phase, contacts, pelvis motion, clearances, joint states, interaction forces, and risk.
VLA safety is an active research area. SafeVLA formulates constrained learning for VLA policies [18], while SAFE uses internal VLA features to detect likely failures [19]. For a wearable robot, learned safety methods should supplement rather than replace deterministic protections. Control barrier functions (CBFs) provide a principled method for projecting proposed controls into a safe set [20], [21]; discrete CBF variants have also been applied to bipedal navigation [22].

III. SYSTEM REQUIREMENTS AND HARDWARE INTEGRATION

A. Mechanical Platform Assumptions
We assume a bilateral lower-limb device with powered hip and knee flexion-extension joints, rigid thigh and shank links, adjustable cuffs, foot interfaces, and a waist structure. The presented architecture remains applicable to passive ankle joints or additional powered degrees of freedom, but each new actuator increases the action dimension and safety-analysis burden.
The CAD rendering in Fig. 2 is used only to communicate integration locations. Final dimensions, transmission ratios, motor ratings, battery capacity, joint limits, and material choices must be derived from mechanical analysis and validated independently. Learning must not compensate for an underdesigned frame, insufficient brakes, excessive backlash, poor alignment, or inadequate emergency support.
B. Sensor and Compute Stack
Table I specifies functional requirements rather than mandating particular vendors. A forward RGB-D or stereo camera should be mounted on the rigid pelvis frame and tilted downward to view the near walking surface. A second downwardfacing camera improves stair-edge and foot-placement geometry. The pelvis IMU estimates global body orientation and acceleration. Absolute joint encoders, motor-side encoders, current sensing, and optional output torque sensors provide proprioception. Foot pressure sensors or load cells estimate heel strike, foot flat, toe-off, and left-right load transfer. Optional cuff force sensors and thigh or shank IMUs improve interaction and intent estimation.
The architecture uses two computing domains. The high-level computer may run a Linux-based perception and learning stack, but is not trusted for deterministic timing. The low-level controller uses a real-time operating environment or microcontroller and remains able to enter a safe state if the

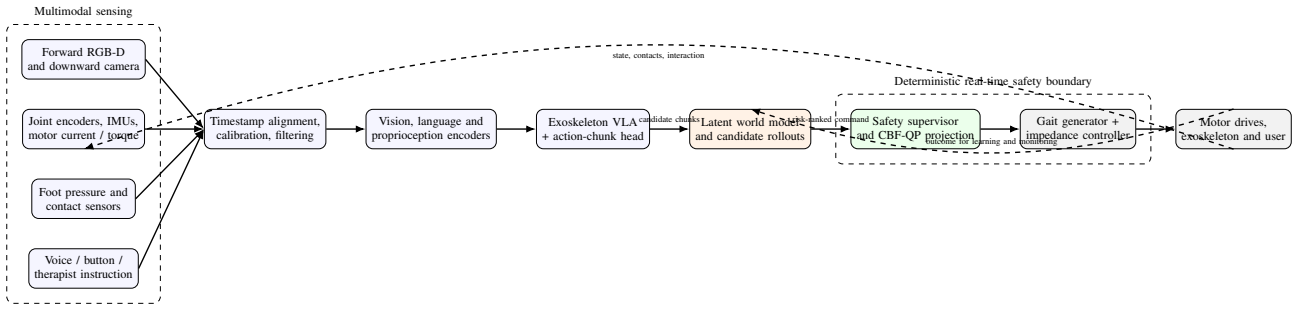
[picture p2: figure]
Forward RGB-D and downward camera; Joint encoders, IMUs, motor current / torque; Foot pressure and contact sensors; Voice / button / therapist instruction; Timestamp alignment, calibration, filtering; Vision, language and proprioception encoders; Exoskeleton VLA + action-chunk head; Latent world model and candidate rollouts; Safety supervisor and CBF-QP projection; Gait generator + impedance controller; Motor drives, exoskeleton and user; candidate chunks; risk-ranked command; state, contacts, interaction; outcome for learning and monitoring; Multimodal sensing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

Fig. 1. Proposed ExoVLA-WM architecture. The VLA does not directly drive motors. It proposes restricted high-level action chunks; a world model predicts outcomes; a deterministic shield validates or modifies the command; and a real-time controller executes the result.

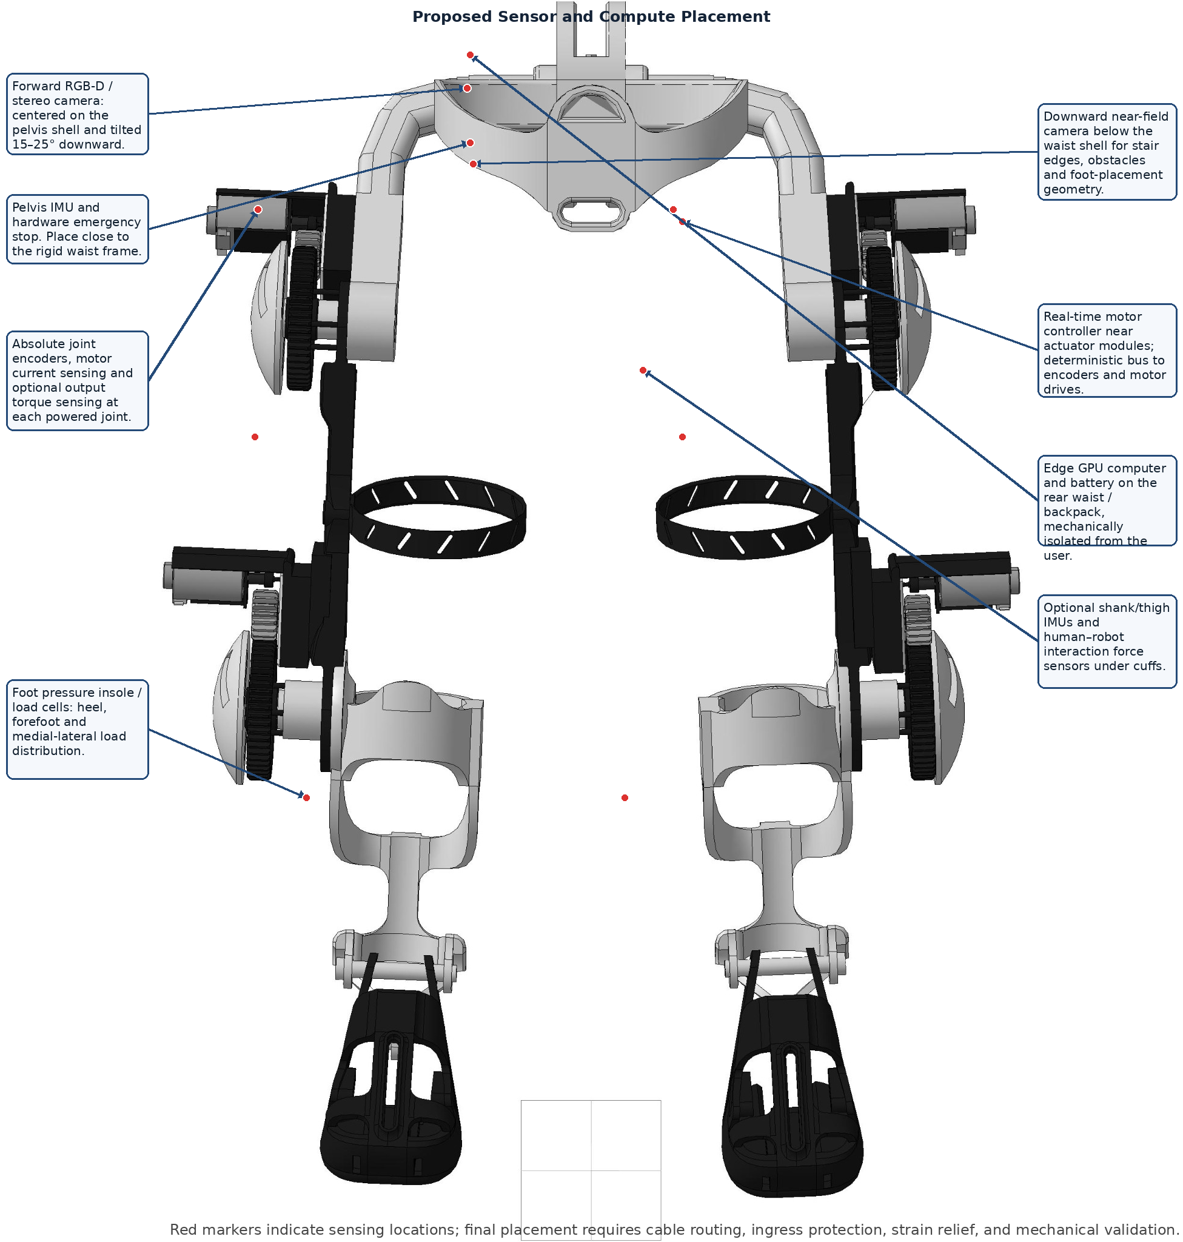
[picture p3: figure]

Fig. 2. Proposed sensor and compute placement on the supplied exoskeleton concept. Red markers denote sensing locations. The edge computer and battery are placed on the rear waist or backpack, while deterministic motor controllers remain close to the actuators.

high-level computer becomes unavailable. A watchdog must
detect stale commands, invalid checksums, timing overruns,
sensor disagreement, and communication loss.
C. Calibration and Time Synchronization

Before data collection, all cameras are calibrated intrinsically and extrinsically relative to a pelvis frame FP . Joint zero positions are measured using mechanical fixtures, and IMU orientation is aligned to the link frame. Pressure sensors are zeroed and calibrated under known loads. Every sensor packet receives a monotonic timestamp. The dataset loader resamples observations to a common high-level clock and stores the original timestamps so that latency can be reconstructed. Recommended calibration checks are:
1) camera reprojection error and depth-plane error;
2) joint-angle agreement between absolute and motor-side

TABLE I
FUNCTIONAL HARDWARE REQUIREMENTS AND TARGET UPDATE RATES
Module | Placement | Target rate | Primary purpose
Forward RGB-D / stereo camera | Center of rigid waist shell,
| downward tilt | 15–30 Hz | Terrain class, depth, stair and obstacle geometry, open-
| | | vocabulary scene semantics
Downward camera | Under waist shell | 30–60 Hz | Near-field edge detection, toe clearance region, landing
| | | region
Pelvis IMU | Near waist-frame center | 200–1000 Hz | Pelvis roll, pitch, yaw rate, acceleration and instability
| | | detection
Joint encoders | Every powered joint | 500–2000 Hz | Joint position and velocity; independent hardware limits
Current / torque sens- ing | Motor or joint output | 500–2000 Hz | Interaction estimate, overload detection, torque control
Foot pressure / load cells | Heel, forefoot and optional
| medial-lateral zones | 100–500 Hz | Contact state, gait phase, load transfer and slip cues
Optional cuff force sensors | Thigh and shank interfaces | 100–1000 Hz | Human-robot interaction force and discomfort proxy
Edge GPU computer | Rear waist / backpack | VLA: 5–20 Hz; world
| | model: 20–100 Hz | Vision, language, multimodal policy, predictive rollouts
Real-time controller | Near motor drives | 500–2000 Hz | Safety supervision, gait generation, impedance / torque
| | | loops
Hardware emergency stop | Reachable by wearer and
| assistant | Asynchronous | Independent motor-disable path and brake engagement

encoders;
3) static IMU gravity-vector alignment;
4) left-right pressure symmetry under known standing loads;
5) end-to-end timing from exposure to action availability;
6) emergency-stop latency measured independently of software.

IV. PROBLEM FORMULATION
At high-level time step t, the observation is

Ot = {I

f
t−k:t

, Id
t−k:t

, Dt−k:t, st−k:t, ℓt, pu}, (1)

where I

f
and I

d
are forward and downward image histories, D is depth, s contains proprioception and contact state, ℓt is a language instruction, and pu is a user profile containing only approved non-sensitive control parameters such as leg lengths, mass range, preferred speed, assistance limits, and fitted joint range.
The VLA does not output raw motor voltage. It outputs a high-level action chunk

A

H

t = {mt:t+H, v∗

t:t+H, L∗

t:t+H, h∗
t:t+H, gL

t:t+H, gR
t:t+H, rt:t+H},
(2)
where m is a discrete locomotion mode, v

∗
is desired speed,
L

∗
is step length, h

∗
is step height or clearance, g

L, gR are left-right assistance gains, and r is an optional bounded residual. The allowed mode set is

M = {STOP, STAND, LEVEL, RAMP_UP, RAMP_DOWN,

STAIR_UP, STAIR_DOWN, TURN_L, TURN_R, SIT}.
(3)

The low-level controller maps an accepted command to joint references q

ref and nominal torques

τnom = Kp(q

ref − q) + Kd( ˙q

ref − q˙) + τf f . (4)

The learned residual is saturated componentwise:

τdes = τnom + α clip(r, −r, ¯ r¯), | 0 ≤ α ≤ αmax. | (5)

The initial system sets α = 0; nonzero residual assistance is enabled only after all higher-level experiments pass predefined safety gates.

V. EXOVLA-WM ARCHITECTURE
A. Multimodal Encoders
A pretrained VLA provides a vision-language backbone. Image tokens are generated from the forward and downward views. A dedicated proprioception projector encodes joint positions, velocities, motor currents, pelvis IMU, pressure features, gait phase, and previous mode. The projected proprioceptive tokens are inserted using learned modality embeddings and temporal positions. A user-profile token provides permitted personalization parameters without exposing raw medical records.
We recommend three initial model variants:
1) OpenVLA adapter: freeze most of the VLA and train LoRA layers, a proprioception projector, and an exoskeleton action head;
2) OFT-style continuous head: predict continuous chunks with parallel decoding and an L1 objective following the design lessons of OpenVLA-OFT [8];
3) from-scratch baseline: train ACT or Diffusion Policy on the same observations to determine whether VLA pretraining adds value.
B. Hierarchical Action Head
The action head has three branches:
- categorical logits for locomotion mode;
- continuous chunk regression for speed, step geometry, and assistance gains;

- calibrated uncertainty and failure likelihood.
The supervised imitation loss is

LV LA = λmLCE(m, mˆ )+λc ∥ac − aˆc∥1+λsLsmooth+λuLcal,
(6)
where ac denotes continuous chunk parameters. The smoothness term penalizes abrupt changes in speed, assistance, and residual commands. The calibration term may combine temperature scaling, Brier loss, and failure-label supervision. Failure detection can additionally use internal VLA features, following the motivation of SAFE [19].
C. Latent World Model

The world model encodes the current multimodal state into zt and predicts future latent state, contact, kinematics, interaction, and risk under candidate action chunks:

zt+1 ∼ fθ(zt, AH
t
), | (7)
yˆt+1 = gθ(zt+1), | (8)

where yˆ contains predicted pelvis orientation, joint state, foot contacts, toe clearance, interaction torque, collision indicator, slip indicator, and confidence. Training uses a weighted objective

LWM = λzLdyn+λqLkin+λcLcontact+λfLforce+λrLrisk.
| (9)
At inference, the system samples or enumerates a small set of candidate chunks near the VLA proposal. Each candidate receives a horizon cost

J(A) = X

H

i=1

wectask + wscstability + wj cjoint + wf cforce

+ wocobstacle + wucuncertainty + wEcenergy t+i

(10)

The lowest-risk feasible candidate is passed to the deterministic safety layer. If all candidates are infeasible, the system selects a safe stop or support state.

D. Uncertainty Estimation

A single confidence score is insufficient. We propose reporting:
- predictive entropy over locomotion mode;
- ensemble variance or dropout variance for continuous action parameters;
- disagreement between the VLA terrain interpretation and a lightweight independent classifier;
- world-model rollout variance;
- out-of-distribution score in visual-proprioceptive feature space;
- calibrated failure probability.
Uncertainty metrics for VLA-enabled robots are still developing [23]. Therefore, thresholds must be tuned using held-out failure scenarios, not assumed to transfer from manipulation benchmarks.

VI. DETERMINISTIC SAFETY SUPERVISOR

A. State Machine and Gating

The safety supervisor maintains modes BOOT, CALIBRATE,
STANDBY, ACTIVE, TRANSITION, SAFE_STOP, and
FAULT. Learned commands are accepted only in ACTIVE or approved TRANSITION states. A transition guard checks contact pattern, gait phase, terrain confidence, user command consistency, and minimum available stopping margin. Immediate fallback is triggered by any of the following:
- hardware emergency stop;
- stale high-level command or missed watchdog deadline;
- joint position, velocity, current, torque, or temperature beyond a warning boundary;
- inconsistent redundant encoders;
- excessive pelvis tilt or angular rate;
- unexpected loss of support contact;
- sensor dropout, invalid depth, or excessive VLA/world-model uncertainty;
- predicted collision, insufficient toe clearance, or unsafe load transfer;
- communication corruption or controller reset.
B. Control Barrier Function Projection

Let the robot-human state be x and the control input be joint torque τ . Define safety functions hi(x) ≥ 0 for joint limits, velocity limits, torque margins, pelvis orientation, toe clearance, and contact-dependent constraints. The desired torque is projected through

τ

∗ = arg min

τ,δ

1
2

∥τ − τdes∥

2
W + ρ ∥δ∥

2
(11)

s.t. h˙
i(x, τ ) + γihi(x) ≥ −δi
, | ∀i, | (12)
τmin ≤ τ ≤ τmax, | |∆τ | ≤ ∆τmax, | (13)
δi ≥ 0. | (14)

This formulation follows the CBF-QP principle [20]. Because the coupled human-exoskeleton dynamics are uncertain, learned model corrections may be added only with conservative margins and validation, consistent with learning-based CBF work [21]. If the optimization is infeasible or exceeds its deadline, the controller uses a pre-certified fallback torque.

C. Safety Limits

Numerical limits must be derived from the actual mechanism, user population, actuator capability, clinical input, and formal risk analysis. The source package therefore exposes configuration variables but intentionally does not assign universal values. Each limit has a warning threshold, a hard threshold, a debounce duration, and a documented fallback. Safety must not rely on a single software process.

VII. DATA COLLECTION AND DATASET DESIGN

A. Staged Data Collection

Data collection proceeds in six gates.

Gate 0: Bench and fixture tests. Validate motors, brakes, encoders, current limits, watchdogs, bus timing, and emergency stop without a human.
Gate 1: Passive sensing. A participant wears the unpowered or transparent-control device while walking with external support. Record sensor data and labels without allowing learned control.
Gate 2: Expert controller. Use an established finite-state gait controller or therapist-operated reference system. The learned model observes but does not act.
Gate 3: Shadow mode. Run VLA and world-model inference online; log proposed actions, uncertainty, and safety rejections while the expert controller remains in command. Gate 4: High-level shared autonomy. Permit the learned system to select among validated gait primitives while the safety layer and expert low-level controller remain authoritative. Gate 5: Bounded residual. Enable a small residual assistance term only after all prior gates meet predefined safety and reliability criteria.
B. Episode Schema
Each episode stores:

episode_id, participant_code session_id, calibration_version hardware_version, software_commit rgb_forward, rgb_down, depth camera_timestamps
joint_position, joint_velocity motor_current, torque
pelvis_imu, optional_limb_imus foot_pressure
expert_mode, gait_phase, terrain transition_label
language_instruction
therapist_override
high_level_action
low_level_reference, executed_torque safety_flags, uncertainty
failure_annotation
outcome_metrics, user_feedback

Personally identifying information should be stored separately under approved governance. Video release requires explicit consent and de-identification procedures.

C. Language and Task Annotation
Language commands are grouped into intent families:
- locomotion: start, stop, slow, speed up, turn;
- terrain: climb stairs, descend stairs, use ramp, step over obstacle;
- semantic goal: go to the chair, stop at the doorway;
- assistance: more or less support, left-right adjustment;
- safety: stop now, hold position, ask for help.
Paraphrases should be recorded to test language generalization, but every open-vocabulary command must map to a restricted machine-readable command before execution.

VIII. TRAINING PIPELINE

A. Stage A: Perception and Gait-State Pretraining
Train separate modules for terrain segmentation, depthderived geometry, contact state, and gait phase. These modules provide interpretable diagnostics and independent checks. Terrain labels include level ground, ramp up/down, stair up/down, obstacle, drop-off, and unknown. Geometry targets include distance to first stair edge, riser height, tread depth, ramp slope, obstacle height, and candidate landing regions.
B. Stage B: VLA Adaptation by Imitation
Initialize from OpenVLA or another available VLA. Train a proprioception projector and high-level action head with parameter-efficient tuning. Balance the dataset by participant, activity, transition, terrain geometry, lighting, and instruction paraphrase. Use sequence windows rather than individual frames. Strong augmentations are applied only when their physical meaning is preserved; depth corruption and camera occlusion are included as explicit failure cases.
C. Stage C: World-Model Training
Train the world model on expert and shadow-mode trajectories. To reduce unsafe extrapolation, initial rollouts are short and candidates stay close to expert actions. Use ensembles or bootstrap heads to estimate epistemic uncertainty. Oversample transitions, near-misses, emergency stops, and sensor failures. A candidate is labeled unsafe when it violates a hard limit, triggers the supervisor, produces insufficient clearance, causes unexpected contact, or is rejected by an expert.
D. Stage D: Simulation and Offline Improvement
A physics simulation should represent the exoskeleton, a human or musculoskeletal surrogate, actuator dynamics, transmission compliance, sensor noise, terrain variation, and communication delay. Domain randomization covers body dimensions, mass distribution, friction, motor parameters, camera pose, latency, and sensor bias. Simulation may train residual policies or expand the world-model dataset, but deployment remains gated by real-data uncertainty. Experiment-free simulation learning has shown promise for exoskeleton assistance [13]; nevertheless, human-worn validation must proceed conservatively.
E. Stage E: Human-in-the-Loop Personalization Personalization optimizes a low-dimensional assistance vector ϕu, not the entire VLA. Candidate parameters may include phase, amplitude, stiffness, damping, and left-right assistance ratio. The objective is

ϕ

∗
u = arg min

ϕ∈Φsafe

wMMˆ (ϕ)+wI

ˆI(ϕ)+wC Cˆ(ϕ)+wA ∥ϕ − ϕ0∥

2
,

(15)
where Mˆ is a metabolic or muscle-effort proxy, ˆI is interaction force, Cˆ is discomfort or instability cost, and ϕ0 is a conservative baseline. Human-in-the-loop optimization has shown that individual customization can matter [24], [25], but recent work also highlights variability and co-adaptation limitations [26].

Algorithm 1 Online ExoVLA-WM Control Loop
1: Initialize verified gait controller and safe-state machine 2: while system enabled do
3: | Read synchronized sensing packet Ot
4: | if hardware fault, stale data, or emergency stop then
5: | enter SAFE_STOP; continue
6: | end if
7: | Estimate gait phase, contact, terrain and independent
| confidence
8: | VLA proposes high-level action chunk AˆH t and uncer-
| tainty
9: | Generate candidate set C(AˆH t ) including safe stop
10: | for all A ∈ C do
11: | Roll out world model; compute J(A) and feasibility
12: | end for
13: | Select lowest-cost feasible candidate A∗
14: | if uncertainty or failure probability exceeds threshold
| then
15: | replace A∗ with conservative fallback
16: | end if
17: | Generate nominal joint references and τdes
18: | Solve safety projection in Eq. (14)
19: | if solver infeasible or late then
20: | execute certified fallback torque
21: | else
22: | execute τ ∗ and log all decisions
23: | end if
24: end while

Therefore, the optimizer uses conservative trust regions and repeated validation rather than one-session convergence claims.

IX. IMPLEMENTATION PLAN

A. Software Processes
The implementation is divided into independently restartable processes:
1) sensor drivers and hardware timestamping;
2) camera preprocessing and depth geometry;
3) proprioceptive state estimation;
4) VLA inference server;
5) world-model rollout server;
6) safety supervisor and real-time controller;
7) logger, dashboard, and replay tools.
The safety controller must not block on a network call, GPU inference, file write, or visualization process. High-level messages contain sequence number, timestamp, validity interval, model version, uncertainty, and checksum.
B. Target Latency Budget
A plausible initial latency budget is shown in Table II. Values are engineering targets, not measured results.
The VLA uses receding-horizon chunks so that the low-level controller can continue tracking a valid reference between high-level updates. If the validity interval expires, the system

TABLE II
ILLUSTRATIVE HIGH-LEVEL LATENCY BUDGET
Component | Target
Camera exposure, transfer and preprocessing | < 40 ms
Depth / terrain geometry | < 25 ms
Proprioception and gait-state update | < 5 ms
VLA chunk generation | < 100 ms
World-model candidate scoring | < 20 ms
High-level safety decision | < 5 ms
Low-level controller cycle | 0.5–2 ms

decelerates or enters a support state rather than replaying stale actions.

C. Model Sizes and Training Configuration

A practical first implementation freezes the majority of a 7B-scale VLA and trains low-rank adapters, the proprioception projector, and a compact action head. Mixed precision and quantization may reduce inference cost, but every quantized model must be revalidated. The world model can begin with a smaller recurrent state-space or transformer model because its horizon and output variables are restricted. Hyperparameters in the source code should be treated as starting points and tuned on a validation set grouped by participant.

X. EXPERIMENTAL EVALUATION
A. Research Questions

The study tests the following hypotheses:
H1:
Multimodal VLA adaptation improves generalization to unseen visual scenes and paraphrased instructions compared with a closed-set terrain classifier.
H2:
The world model reduces unsafe transition proposals and near-miss events compared with direct VLA-to-gaitprimitive selection.
H3:
The deterministic safety shield reduces hard-limit and contact-consistency violations without causing unacceptable task failure or latency.
H4:
Personalized assistance improves at least one user-centered outcome without increasing interaction force or instability. H5:
The proposed architecture degrades safely under camera occlusion, depth corruption, language ambiguity, communication delay, and sensor dropout.
B. Baselines
C. Staged Test Protocol

Phase 1: Simulation. Evaluate thousands of randomized episodes, including sensor faults and rare terrain transitions. No human exposure.

TABLE III
PLANNED BASELINES
Method | Vision/language | World model | Safety
B0 FSM | Closed-set sensors only | No | Hard limits
B1 CV+FSM | Terrain classifier / geometry | No | Hard limits
B2 ACT / Diffu- sion | Vision + state; op- tional language | No | Hard limits
B3 VLA-direct | VLA | high-level
| command | No | Hard limits
B4 VLA+WM | VLA + predictive ranking | Yes | Hard limits
Ours | VLA + predictive ranking | Yes | Full supervisor + CBF-QP

Phase 2: Hardware-in-the-loop and dummy-load tests. Use link fixtures, instrumented test rigs, and suspended leg surrogates. Verify timing, limit enforcement, and safe-stop behavior.
Phase 3: Able-bodied participants. Conduct supervised trials with overhead fall protection or parallel bars, an assistant, hardware emergency stop, conservative speed, and zero learned residual initially.
Phase 4: Target clinical population. Proceed only after engineering review, institutional ethics approval, clinician involvement, inclusion/exclusion criteria, and successful prior gates. The protocol must be adapted to the intended medical claim and local regulation.
Tasks include standing, starting, stopping, level walking, turning, ramp ascent/descent, stair ascent/descent, sit-to-stand, obstacle crossing, semantic goal following, and ambiguouscommand rejection. Environmental variation includes lighting, surface texture, clutter, obstacle dimensions, camera occlusion, and unseen stair geometry within approved bounds.
D. Metrics
E. Ablations
Ablations remove one component at a time: language, depth, downward camera, foot pressure, pelvis IMU, proprioceptive history, action chunking, world model, failure detector, CBF projection, and personalization. Additional tests compare a unified VLA encoder against separate vision and intent models. The central question is not merely whether the full model succeeds, but which components add safety and generalization beyond a strong deterministic baseline.
F. Statistical Analysis
Use participant-wise train/validation/test splits and report confidence intervals. Human trials should use repeatedmeasures analysis because every participant experiences multiple controllers. A mixed-effects model can include controller as a fixed effect and participant as a random effect. Binary success outcomes can use mixed-effects logistic regression. Continuous metrics can use linear mixed models or appropriate nonparametric alternatives after residual checks. Multiple comparisons should be corrected. Effect sizes and confidence intervals are reported alongside p-values.
G. Result Tables Without Fabrication

Table V is a reporting template to complete after experiments.

XI. FAILURE SCENARIOS AND RISK CONTROLS

Formal risk management should follow the intended product category. ISO 13482 addresses personal-care robot hazards but explicitly does not cover robots classified as medical devices; medical use requires an appropriate medical-device risk process such as ISO 14971 [27], [28]. In the United States, powered lower-extremity exoskeletons are regulated as Class II devices under product code PHL and 21 CFR 890.3480 [29]. This paper is not a regulatory submission and does not establish compliance.

XII. ETHICS, PRIVACY AND REPRODUCIBILITY

Human studies require institutional ethics approval, informed consent, stopping rules, trained supervision, and a plan for adverse events. Participants must be told which portions of control are learned, what data are recorded, and when an operator may override the system. The system should minimize collection of identifiable video and separate identity from episode data. Voice commands may be transcribed locally and raw audio deleted when not required.
Reproducibility artifacts should include:
- mechanical and electrical interface specifications that do not expose unsafe build details;
- calibration procedures and sensor schemas;
- dataset splits by participant and environment;
- model configuration, training seeds, software commits, and evaluation scripts;
- safety configuration version and complete intervention logs;
- negative results and failure cases, not only successful demonstrations.

XIII. DISCUSSION

A. Why a Hierarchy Is Necessary

An end-to-end VLA-to-torque controller is conceptually simple but inappropriate as the first implementation. Largemodel inference has variable latency, opaque failure modes, and training-data mismatch. A hierarchy confines semantic reasoning to a slow, restricted action space and preserves deterministic control at the physical interface. This also allows each layer to be evaluated independently.

B. Where Novelty Must Be Demonstrated

The work is not novel merely because a camera or a VLA is attached to an exoskeleton. Empirical novelty should be demonstrated through at least three axes:
1) an exoskeleton-specific VLA interface that fuses vision, language, proprioception, and contact history;
2) predictive world-model rejection that measurably reduces risky transitions or failure severity;
3) safe personalization that improves a human-centered metric without degrading stability or interaction safety.

TABLE IV
EVALUATION METRICS
Category | Metrics | Interpretation
Task performance | Completion rate, time, path deviation, transition success, instruction-following accuracy | Whether the requested mobility task is completed correctly
Perception | Terrain F1, geometry MAE, transition anticipation time, unknown detection AUROC
Whether the system understands terrain before contact
Safety | Hard-limit violations, supervisor inter- ventions, near-falls, unexpected contacts, minimum toe clearance, stop distance
Whether failures are detected and contained
Control | Joint tracking RMSE, torque RMSE, torque-rate peaks, interaction force, gait- phase error
Quality and smoothness of physical execution
Human state | Pelvis | roll/pitch, | step | symmetry,
double-support time, optional EMG or metabolic cost

Stability, effort and biomechanical effect

Uncertainty | ECE, Brier score, failure AUROC, time- to-detection, selective success vs. cover- age
Calibration and usefulness of abstention
Systems | End-to-end latency, deadline misses, power consumption, thermal throttling, dropped frames

Real-time feasibility and robustness

User outcomes | Comfort score, perceived safety, thera- pist workload, usability questionnaire

Practical acceptability

Generalization | Unseen users, terrains, lighting and para- phrases

Whether performance transfers beyond training conditions

TABLE V
PRIMARY RESULT TEMPLATE. NO NUMERICAL VALUES ARE CLAIMED IN THIS PRE-EXPERIMENTAL DRAFT.
Method | Task success | Transition F1 | Safety interventions | Near-misses | Latency | Comfort
B0 FSM | To be measured | To be measured | To be measured | To be measured | To be measured | To be measured
B1 CV+FSM | To be measured | To be measured | To be measured | To be measured | To be measured | To be measured
B2 ACT / Diffusion | To be measured | To be measured | To be measured | To be measured | To be measured | To be measured
B3 VLA-direct | To be measured | To be measured | To be measured | To be measured | To be measured | To be measured
B4 VLA+WM | To be measured | To be measured | To be measured | To be measured | To be measured | To be measured
ExoVLA-WM | To be measured | To be measured | To be measured | To be measured | To be measured | To be measured

A strong paper should also release a benchmark containing
paired scene, instruction, body-state, action, risk, and outcome labels.
C. Limitations
The proposed architecture has important limitations. Manipulation-pretrained VLA representations may transfer poorly to gait. Real exoskeleton data are expensive and safety constrained. User behavior is nonstationary, and personalization may reflect adaptation rather than a stable optimum. World models can be confidently wrong outside the training distribution. CBF guarantees depend on model assumptions and reliable state estimation. Vision may fail under sunlight, blur, reflective surfaces, or crowd occlusion. Finally, clinical benefit cannot be inferred from able-bodied laboratory experiments.

XIV. CONCLUSION
This paper specified ExoVLA-WM, a complete research plan for integrating VLA models and predictive world models into a bilateral lower-limb exoskeleton without giving the learned model unrestricted motor authority. The design combines multimodal sensing, language-grounded high-level action chunks, predictive risk evaluation, calibrated abstention, deterministic safety projection, conventional real-time control, and staged human-in-the-loop personalization. The proposed experiments are structured to determine whether VLA semantics and world-model foresight improve generalization and safety beyond strong finite-state, computer-vision, and imitation-learning baselines. The next required step is not additional architectural complexity, but disciplined implementation of bench validation, synchronized data collection, shadow-mode evaluation, and safety-gated human trials.

APPENDIX A
MINIMUM BUILD AND INTEGRATION CHECKLIST
1) Verify structural factors of safety, mechanical stops, joint alignment, cuff comfort, pinch-point protection, transmission backlash, and brake behavior.

TABLE VI
PRELIMINARY FAILURE-MODE AND EFFECTS ANALYSIS
Failure mode | Possible effect | Detection | Control / fallback
Camera occlusion or glare | Wrong terrain or missed obsta- cle
Image-quality | monitor,
| | depth invalid ratio, model disagreement | Reduce speed, independent proprioceptive mode, safe stop before transition
Ambiguous language | Incorrect task selection | Low instruction confidence, contradiction with current state

Ask for confirmation or reject; never infer an irreversible action

VLA hallucination / OOD
scene

Unsafe high-level command OOD score, failure detector, world-model risk, rule incon- sistency

Candidate rejection and conservative gait primitive

World-model error | False-safe rollout | Ensemble disagreement, val-
idation residual monitor

Increase margins; safety supervisor remains authoritative

Pressure sensor failure | Incorrect gait phase / contact | Redundancy, | plausibility
checks, no-load drift

Use encoder/IMU fallback; block terrain transition

Encoder discrepancy | Wrong joint state | Absolute vs. motor encoder
disagreement

Disable affected joint, brake or safe support state

High-level computer crash | No new command | Watchdog timeout | Continue bounded valid chunk briefly, then decelerate / safe stop
QP infeasibility or overrun | No certified projected torque | Solver status and timing
monitor

Immediate verified fallback torque; log event

Unexpected user behavior | Instability or discomfort | Interaction | force, | pelvis
IMU, contact mismatch

Reduce assistance, increase compliance, stop and request help

Battery or thermal issue | Loss of actuation or degraded torque

Voltage, current and temperature monitors

Controlled stop before critical threshold; mechanical support

2) Establish independent hardware current limits and emergency motor disable.
3) Install absolute encoders and confirm startup state without motion.
4) Route cables with strain relief and joint-motion clearance.
5) Mount cameras and IMUs to rigid members, not flexible covers.
6) Implement a deterministic communication protocol with timestamps, sequence numbers and watchdogs.
7) Validate safe-stop behavior under compute loss, sensor loss and battery reduction.
8) Collect passive and expert-control data before enabling learned decisions.
9) Run shadow mode and quantify false transitions, uncertainty calibration and safety rejections.
10) Enable high-level primitive selection before any residual torque.

APPENDIX B
SUGGESTED TRAINING CONFIGURATION

The following values are starting points, not validated optima:
- sequence context: 0.5–2.0 s of synchronized history;
- high-level action horizon: 0.25–1.0 s;
- LoRA rank: 16–64 on selected attention and feed-forward layers;
- proprioception token dimension: 256–1024;
- optimization: AdamW, gradient clipping, cosine decay;
- balanced sampling by user, terrain, transition, instruction and failure type;
- validation split: unseen participants and unseen physical locations;
- early stopping: composite of action error, calibration and safety-event recall;
- world-model ensemble: 3–5 members or bootstrap heads;
- deployment: quantization only after accuracy, calibration and timing revalidation.

APPENDIX C
SAFETY-GATED MILESTONES

TABLE VII
GO/NO-GO MILESTONES
Gate | Required evidence before progression
G0 | Independent emergency stop, current limit and watchdog pass repeated
| fault-injection tests
G1 | Sensor calibration and synchronization remain within specified
| tolerance
G2 | Expert controller completes approved tasks with no unresolved safety
| event
G3 | Shadow VLA has acceptable transition precision, calibrated abstention
| and bounded latency
G4 | World-model risk ranking improves failure recall on held-out faults
G5 | Shared autonomy meets intervention and near-miss thresholds under
| harness
G6 | Residual assistance remains within certified bounds and improves a
| predefined metric

APPENDIX D
EXAMPLE MACHINE-READABLE HIGH-LEVEL COMMAND

{
"sequence": 18231,
"timestamp_ns": 921834772110, "valid_until_ns": 921834972110, "mode": "STAIR_UP",
"speed_mps": 0.22,
"step_length_m": 0.28,
"step_height_m": 0.17,
"assist_left": 0.65,
"assist_right": 0.62,
"residual_enabled": false, "vla_uncertainty": 0.08,

"failure_probability": 0.03, "world_model_risk": 0.11,
"model_version": "exovla_wm_v0.3", "checksum": "..."
}

The real implementation should use a deterministic binary message definition and authenticated software updates. The JSON representation is shown only for readability.

REFERENCES

[1] R. Baud, A. R. Manzoori, A. Ijspeert, and M. Bouri, “Review of control strategies for lower-limb exoskeletons to assist gait,” Journal of NeuroEngineering and Rehabilitation, vol. 18, no. 1, p. 119, 2021.
[2] B. Laschowski, W. McNally, A. Wong, and J. McPhee, “Environment classification for robotic leg prostheses and exoskeletons using deep convolutional neural networks,” Frontiers in Neurorobotics, vol. 15, 2022.
[3] J. Wang, M. Mattamala, C. Kassab, G. Burger, F. Elnecave, L. Zhang,
M. Petriaux, and M. Fallon, “Exosense: A vision-based scene understanding system for exoskeletons,” 2025.
[4] A. Brohan, N. Brown, J. Carbajal, Y. Chebotar, X. Chen, K. Choromanski,
T. Ding, D. Driess, A. Dubey, C. Finn et al., “Rt-2: Vision-languageaction models transfer web knowledge to robotic control,” in Conference on Robot Learning, 2023.
[5] M. J. Kim, K. Pertsch, S. Karamcheti, T. Xiao, A. Balakrishna, S. Nair,
R. Rafailov, E. Foster, G. Lam, P. Sanketi et al., “Openvla: An opensource vision-language-action model,” in Conference on Robot Learning, 2025.
[6] K. Black, N. Brown, D. Driess, A. Esmail, M. Equi, C. Finn, N. Fusai,
L. Groom, K. Hausman, B. Ichter et al., “π0: A vision-language-action flow model for general robot control,” in Robotics: Science and Systems, 2025.
[7] Open X-Embodiment Collaboration, “Open x-embodiment: Robotic learning datasets and rt-x models,” 2023.
[8] M. J. Kim, C. Finn, and P. Liang, “Fine-tuning vision-language-action models: Optimizing speed and success,” 2025.
[9] J. Wang, D. Wu, Y. Gao, X. Wang, X. Li, G. Xu et al., “Integral real-time locomotion mode recognition based on ga-cnn for lower limb exoskeleton,” Journal of Bionic Engineering, 2022.
[10] F. Weigand, A. Hohl, J. Zeiss, U. Konigorski, and M. Grimmer, “Continuous locomotion mode recognition and gait phase estimation based on a shank-mounted imu with artificial neural networks,” 2022.
[11] M. Razmi and I. Shojaei, “Event-driven on-sensor locomotion mode recognition using a shank-mounted imu with embedded machine learning for exoskeleton control,” 2026.
[12] L. Vianello, C. Lhoste, E. B. Kucuktabak, M. Short, L. Hargrove, and J. L. Pons, “Deep-learning control of lower-limb exoskeletons via simplified therapist input,” 2024.
[13] S. Luo, M. Jiang, S. Zhang, J. Zhu, S. Yu, I. D. Silva, T. Wang, E. Rouse,
B. Zhou, H. Yuk et al., “Experiment-free exoskeleton assistance via learning in simulation,” Nature, vol. 630, no. 8016, pp. 353–359, 2024.
[14] C. Chi, Z. Xu, S. Feng, E. Cousineau, Y. Du, B. Burchfiel, R. Tedrake, and S. Song, “Diffusion policy: Visuomotor policy learning via action diffusion,” The International Journal of Robotics Research, 2024, arXiv:2303.04137.
[15] T. Z. Zhao, V. Kumar, S. Levine, and C. Finn, “Learning fine-grained bimanual manipulation with low-cost hardware,” 2023.
[16] D. Hafner, J. Pasukonis, J. Ba, and T. Lillicrap, “Mastering diverse domains through world models,” 2023.
[17] N. Hansen, H. Su, and X. Wang, “Td-mpc2: Scalable, robust world models for continuous control,” in International Conference on Learning Representations, 2024.
[18] B. Zhang, Y. Zhang, J. Ji, Y. Lei, Y. Cai, J. Dai, Y. Chen, and Y. Yang, “Safevla: Towards safety alignment of vision-language-action model via constrained learning,” in Advances in Neural Information Processing Systems, 2025.
[19] Q. Gu, Y. Ju, S. Sun, I. Gilitschenski, H. Nishimura, M. Itkina, and
F. Shkurti, “Safe: Multitask failure detection for vision-language-action models,” 2025.
[20] A. D. Ames, S. Coogan, M. Egerstedt, G. Notomista, K. Sreenath, and
P. Tabuada, “Control barrier functions: Theory and applications,” in European Control Conference, 2019, pp. 3420–3431.
[21] A. Taylor, A. Singletary, Y. Yue, and A. Ames, “Learning for safety-critical control with control barrier functions,” in Learning for Dynamics and Control, 2020.
[22] A. Agrawal and K. Sreenath, “Discrete control barrier functions for safety-critical control of discrete systems with application to bipedal robot navigation,” in Robotics: Science and Systems, 2017.
[23] P. Valle, C. Lu, S. Ali, and A. Arrieta, “Evaluating uncertainty and quality of visual language action-enabled robots,” 2025.
[24] J. Zhang, P. Fiers, K. A. Witte, R. W. Jackson, K. L. Poggensee,
C. G. Atkeson, and S. H. Collins, “Human-in-the-loop optimization of exoskeleton assistance during walking,” Science, vol. 356, no. 6344, pp. 1280–1284, 2017.
[25] K. L. Poggensee and S. H. Collins, “How adaptation, training, and customization contribute to benefits from exoskeleton assistance,” Science Robotics, vol. 6, no. 58, p. eabf1078, 2021.
[26] A. Christou, A. Sochopoulos, E. Lister, and S. Vijayakumar, “Human-inthe-loop optimisation in robot-assisted gait training,” 2025.
[27] International Organization for Standardization, “Iso 13482:2014: Robots and robotic devices—safety requirements for personal care robots,” 2014, current edition at the time of writing; revision in progress.
[28] ——, “Iso 14971:2019: Medical devices—application of risk management to medical devices,” 2019.
[29] U.S. Food and Drug Administration, “Product classification: Powered lower extremity exoskeleton, product code phl, 21 cfr 890.3480,” 2026, accessed June 2026.

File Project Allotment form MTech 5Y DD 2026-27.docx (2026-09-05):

Department of Mechanical Engineering

IIT Kharagpur

Allotment of M.Tech Project for 5Y DD ME-1 Students for Session 2026-27

Name of the student: Ayush Debnath

Roll number: 22ME31010

Name of the project supervisor: Prof. D.K. Pratihar

Broad area of the project to be carried out: Robotics

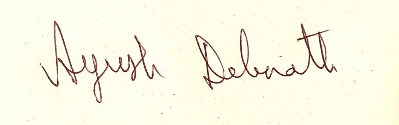
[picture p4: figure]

Signature of the supervisor Signature of the student

Date: Date: 11-05-26

Please send the filled-in form to drsankhadeb@gmail.com after signature.

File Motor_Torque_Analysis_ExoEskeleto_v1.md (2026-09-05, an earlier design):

# Preliminary Motor and Joint-Torque Analysis

## Basis of analysis

Source drawing: `ExoEskeleto Drawing v1.pdf`, 17 sheets, dated 13-07-2026.

This is a preliminary actuator-sizing analysis, not a final safety certification. The drawing provides overall geometry and individual steel-part dimensions, but it does not provide user mass, payload, part masses, centre-of-mass locations, gait cycle, required assistance percentage, motor data, gearbox data, or bearing/friction data.

### Geometry observed in the drawing

- Overall envelope: approximately 1009 mm high, 1009 mm long, and 662 mm wide (sheet 2).
- Principal long members shown on detail sheets: approximately 400-420 mm.
- Circular joint/interface features: approximately 50 mm outside diameter with 10 mm bores on several details.
- Bill of materials: 7 `ELECTROIMAN` units and 11 magnetic laminations/plates, with the listed structural parts identified as steel.
- The assembly appears to provide bilateral lower-limb links connected to a waist ring and foot/boot interfaces.

The seven electromagnets shown in the BOM are not, by themselves, rotary actuators. They may be intended as locks, clutches, or brakes, but the drawing does not define their force, air gap, friction surface, duty cycle, or fail-safe state.

## Reference design case

The following case is used only to obtain first-pass actuator ratings:

| Parameter | Assumption |
|---|---:|
| User mass | 80 kg |
| Thigh length | 0.42 m |
| Shank length | 0.40 m |
| Foot COM distance from ankle | 0.13 m |
| One thigh mass | 10.0% of body mass = 8.00 kg |
| One shank mass | 4.65% of body mass = 3.72 kg |
| One foot mass | 1.45% of body mass = 1.16 kg |
| Thigh and shank COM position | 43.3% of segment length from proximal joint |
| Gravity | 9.81 m/s^2 |
| Dynamic multiplier | 2.0 |
| Engineering factor after dynamics | 1.5 |

These segment fractions exclude the mass of the exoskeleton itself. Actuator, gearbox, battery, and frame masses must be added when CAD mass properties become available.

## Static gravity calculation

The worst gravity moment for a segment occurs when it is approximately horizontal. For a point mass,

`T = m g r`, where `r` is the horizontal distance from the joint axis.

### Hip, one leg held horizontal

`T_hip = g [m_thigh(0.433 L_thigh) + m_shank(L_thigh + 0.433 L_shank) + m_foot(L_thigh + L_shank + r_foot)]`

`T_hip = 46.7 N.m` for the 80 kg reference user.

### Knee, shank and foot held horizontal

`T_knee = g [m_shank(0.433 L_shank) + m_foot(L_shank + r_foot)]`

`T_knee = 12.3 N.m` for the reference user.

### Ankle

Foot self-weight alone gives only about `1.5 N.m`, but this is not the governing ankle case. During standing and walking, ground-reaction force acts at a horizontal distance from the ankle. At full 80 kg load and a 50-120 mm centre-of-pressure offset:

`T_ankle = (80 x 9.81)(0.05 to 0.12) = 39 to 94 N.m`.

In symmetric double support, each side may carry about half this load; in single support, one side can approach or exceed the full value dynamically.

## Lagrange-Euler torque and power calculation

For a planar three-link leg with relative generalized coordinates `q = [q1, q2, q3]^T` for hip, knee, and ankle, define:

`L = K - V`

Applying `tau_i = d/dt(partial L / partial qdot_i) - partial L / partial q_i` gives:

`tau_act = M(q) qdd + C(q, qdot) qdot + G(q) - J_foot^T F_external`.

The external-force term is required during stance. It is zero in the following illustrative swing calculation because the drawing supplies no ground-reaction-force history.

### Numerical state

| Quantity | Hip | Knee | Ankle |
|---|---:|---:|---:|
| Joint angle | 0 deg | 0 deg | 0 deg |
| Joint speed | 1.5 rad/s | 2.0 rad/s | 2.5 rad/s |
| Joint acceleration | 3.0 rad/s^2 | 4.0 rad/s^2 | 5.0 rad/s^2 |

At the fully extended horizontal configuration:

`M = [[2.8397, 1.0382, 0.1610], [1.0382, 0.5094, 0.0976], [0.1610, 0.0976, 0.0373]] kg.m^2`

`G = [46.7308, 12.3518, 1.4793]^T N.m` and `C(q,qdot)qdot = 0` at this particular configuration.

| Joint | Inertial torque | Gravity torque | Total torque | Joint power, `P=tau*qdot` |
|---|---:|---:|---:|---:|
| Hip | 13.477 N.m | 46.731 N.m | **60.208 N.m** | **90.311 W** |
| Knee | 5.640 N.m | 12.352 N.m | **17.992 N.m** | **35.985 W** |
| Ankle | 1.060 N.m | 1.479 N.m | **2.539 N.m** | **6.348 W** |
| Total | | | | **132.644 W** |

For the first joint:

`tau_1 = 2.8397(3) + 1.0382(4) + 0.1610(5) + 46.7308 = 60.208 N.m`

`P_1 = tau_1 qdot_1 = 60.208(1.5) = 90.311 W`.

Using 80:1 hip/knee reducers, a 60:1 ankle reducer, and 75% gearbox efficiency gives motor-side values of 1.003 N.m at 1146 rpm and 120.4 W for the hip, 0.300 N.m at 1528 rpm and 48.0 W for the knee, and 0.056 N.m at 1432 rpm and 8.5 W for the ankle.

These values include human-segment mass only. Add the exoskeleton link and actuator masses to the Lagrangian and measured ground-reaction force through `J_foot^T F_external` for final stance calculations.

## Recommended joint-output ratings

The table below is a practical preliminary envelope for a device intended to support an 80 kg user. Values are output-side ratings after the gearbox. They are intentionally above the simple static limb-weight calculations because walking, starts/stops, imbalance, ground reaction, and exoskeleton mass dominate real operation.

| Joint, each side | Continuous output torque | Peak output torque | Useful output speed | Approx. actuator class |
|---|---:|---:|---:|---|
| Hip flexion/extension | 45-60 N.m | 120-150 N.m | 0-3 rad/s | 300-500 W BLDC + low-backlash reducer |
| Knee flexion/extension | 30-45 N.m | 80-110 N.m | 0-4 rad/s | 250-400 W BLDC + low-backlash reducer |
| Ankle plantar/dorsiflexion | 45-60 N.m | 120-150 N.m | 0-5 rad/s | 350-600 W BLDC + reducer or remote transmission |

For partial assistance, multiply the joint torque targets by the desired assistance fraction. For example, 40% assistance at a 150 N.m ankle peak requires approximately 60 N.m actuator output, before adding friction and transmission losses.

For user mass `M` different from 80 kg, a first approximation is:

`T_new = T_table (M / 80) + torque caused by exoskeleton and payload masses`.

## Motor and gearbox sizing

For a gearbox ratio `N` and efficiency `eta`, required motor torque is:

`T_motor = T_joint / (N eta)`.

Example for a 120 N.m peak joint, 80:1 reduction, and 75% efficiency:

`T_motor,peak = 120 / (80 x 0.75) = 2.0 N.m`.

At 60:1 and 80% efficiency, the same joint requires `2.5 N.m` motor peak torque. Select the motor using its thermal continuous-torque curve, not stall torque. A reducer in the approximate 50:1-100:1 range is a reasonable starting point, but the final ratio must satisfy both torque and joint-speed requirements.

Recommended architecture:

- 48 V BLDC/PMSM actuators to reduce current and cable mass.
- Absolute joint encoder plus motor encoder.
- Low-backlash harmonic, cycloidal, or well-supported planetary reducer.
- Torque sensing through a strain element or series-elastic element.
- Normally engaged mechanical brake at load-bearing joints.
- Mechanical hard stops independent of software.

High reduction improves torque density but reduces backdrivability and increases reflected inertia. For a wearable system, torque sensing and compliance are strongly preferred.

## Electromagnet feasibility check

If an electromagnet at a nominal 50 mm diameter interface is expected to resist joint torque through friction at an effective radius of roughly 25 mm, the required tangential force is:

`F_t = T / r`.

| Joint torque | Tangential force at 25 mm radius |
|---:|---:|
| 60 N.m | 2400 N |
| 120 N.m | 4800 N |
| 150 N.m | 6000 N |

The required magnetic normal force is even higher because friction torque is `T = mu F_normal r`. With a dry friction coefficient of 0.3, holding 120 N.m at 25 mm requires about `16,000 N` normal force. Air gaps, contamination, heating, and loss of electrical power further reduce reliability.

Therefore, the drawn electromagnets should not be treated as the sole load-bearing joint brakes without a demonstrated force/torque test. If they are used for mode selection or locking, use a mechanically positive, normally locked feature so power loss cannot release the user.

## Structural and integration observations

- Several joint details show 10 mm bores. A 10 mm pin carrying human-support loads requires a combined shear, bearing, bending, fatigue, and retaining-feature analysis; diameter alone is not enough.
- Long 400-420 mm links and offset cuffs create bending and torsion in addition to in-plane joint torque.
- The BOM marks all parts as steel, but does not give grade, thickness for every part, heat treatment, weld details, or allowable stress.
- Joint alignment must follow the user's anatomical hip, knee, and ankle axes. Misalignment can produce harmful cuff forces even when motor torque is within limits.
- Motor mass mounted distally greatly increases swing torque. Knee motors should preferably be proximal, and ankle actuation may benefit from a cable/Bowden or linkage transmission.
- The design should not rely on motor torque to prevent collapse during power loss.

## Data required for final sizing

1. Maximum user mass and any carried payload.
2. Intended function: rehabilitation assistance, full weight support, sit-to-stand, walking, or static locking.
3. Required degrees of freedom and angular ranges at each joint.
4. Target gait speed and motion profiles (angle, velocity, acceleration versus time).
5. CAD mass and centre of mass for every moving link, motor, gearbox, battery, and attachment.
6. Electromagnet model, force-versus-gap curve, coil power, friction material, effective radius, and fail-safe behavior.
7. Gearbox ratio, efficiency, backlash, rated output moment, and life.
8. Ground-reaction-force/load cases and required assistance percentage.

## Preliminary conclusion

For an 80 kg design user and full lower-limb support, size each side approximately for 120-150 N.m peak at the hip, 80-110 N.m peak at the knee, and 120-150 N.m peak at the ankle, with the continuous ratings shown above. Six powered flexion/extension joints are implied if both legs' hip, knee, and ankle are actuated. The seven electromagnets shown in the drawing are better treated as auxiliary locks or clutches, not as substitutes for torque-controlled motors or certified fail-safe brakes.

Do not fabricate or test on a person from these preliminary numbers alone. Complete multibody load simulation, structural FEA, brake validation, electrical/thermal analysis, and controlled bench testing first.

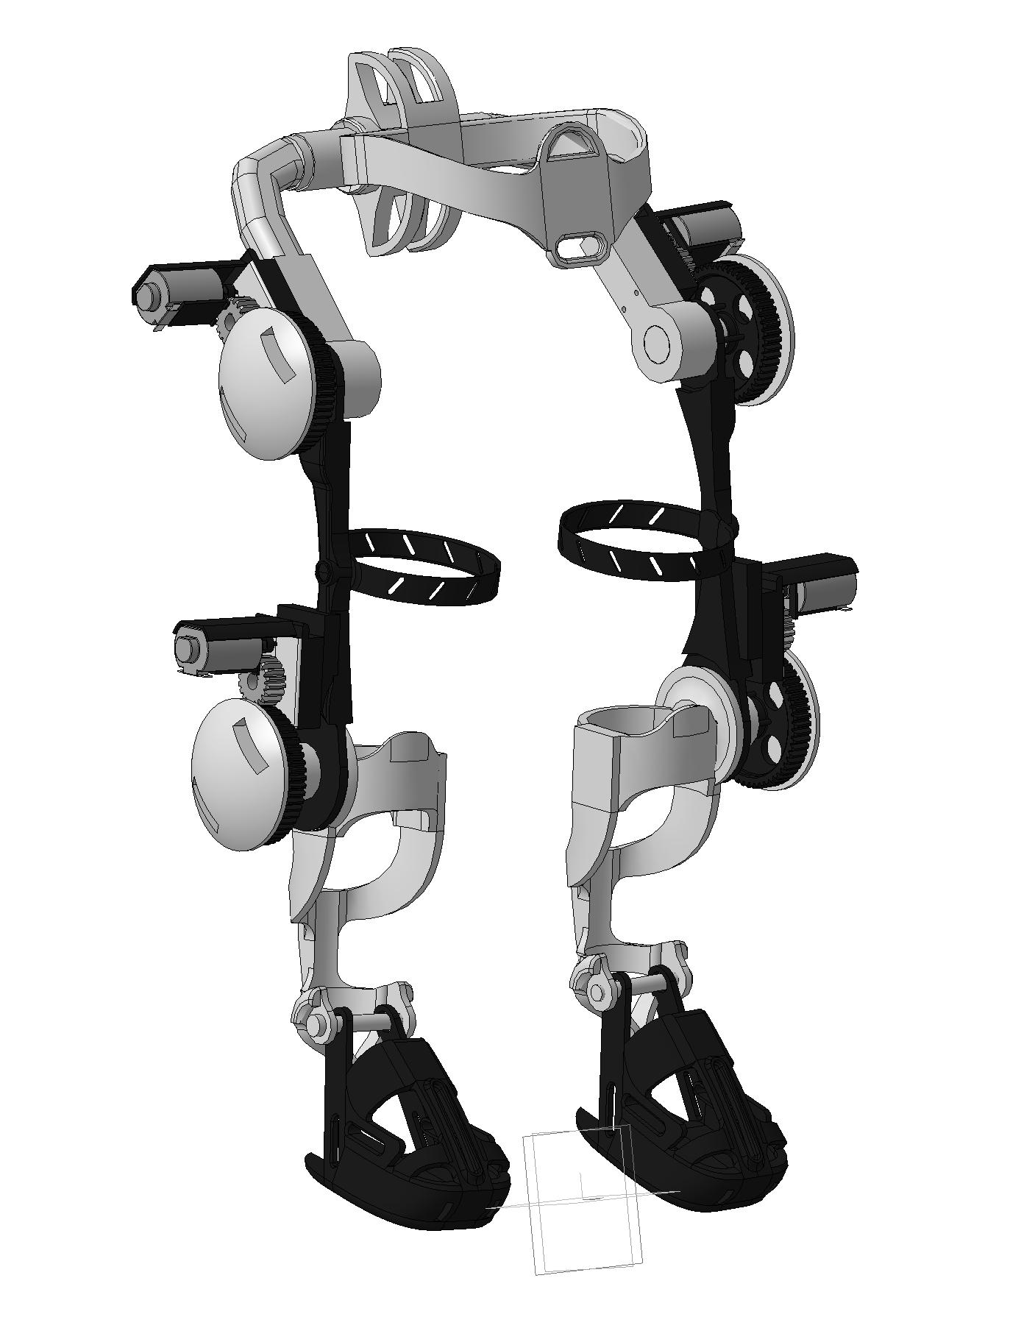
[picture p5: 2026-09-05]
exoskeleton2.jpg

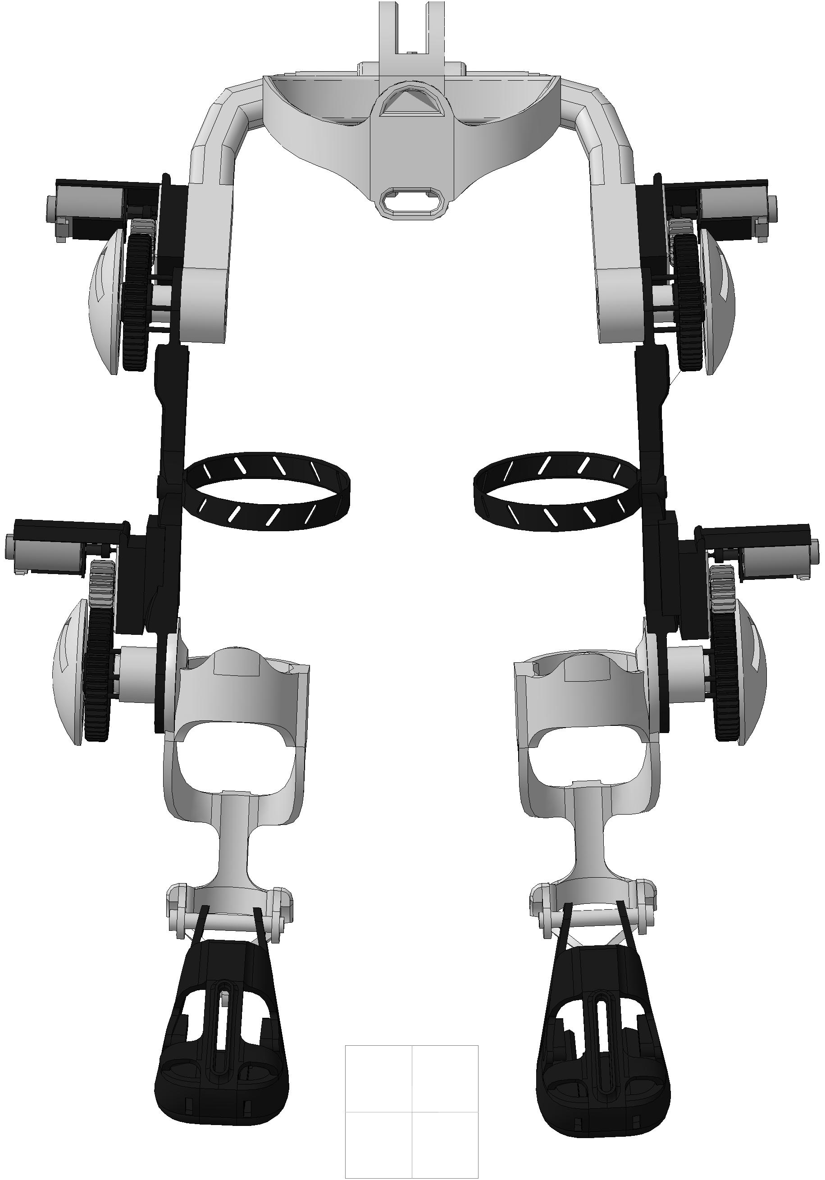
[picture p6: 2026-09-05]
экзо сборка ФИНАЛ.jpg

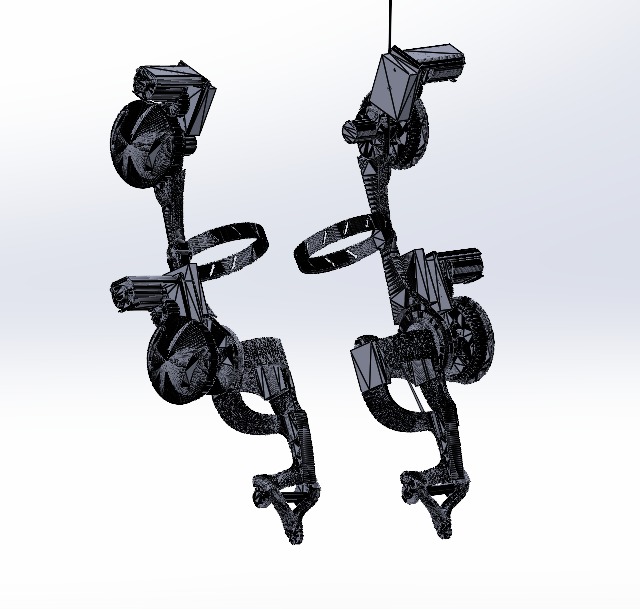
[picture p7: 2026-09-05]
WhatsApp Image 2026-06-17 at 12.58.15 PM.jpeg

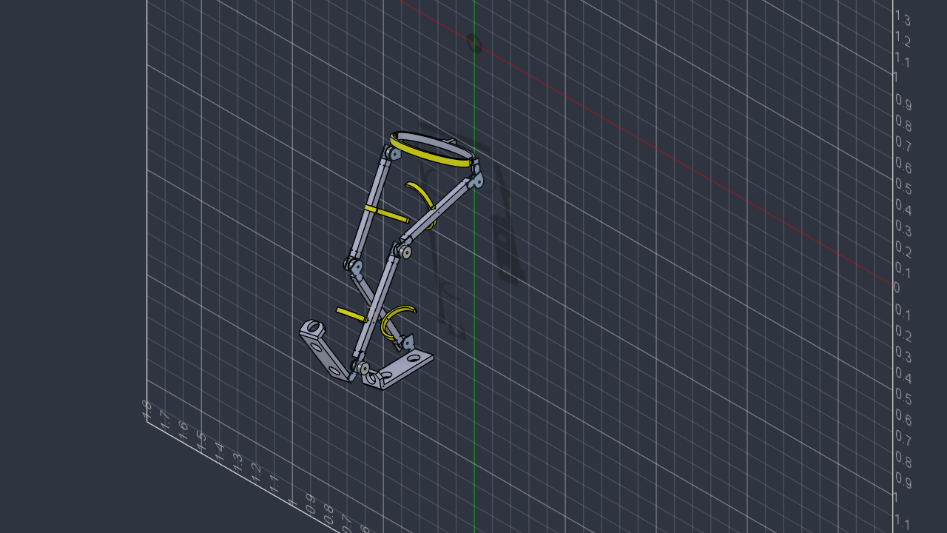
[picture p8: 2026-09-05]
ExoWalk_frames/frame_050.png

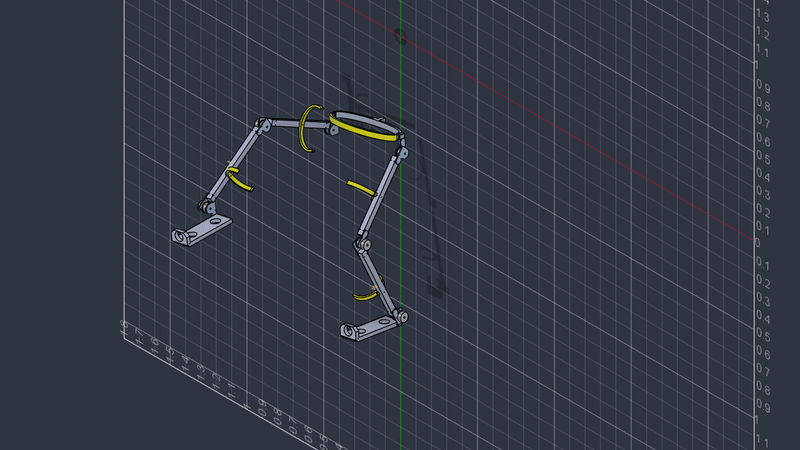
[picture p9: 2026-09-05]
ExoWalk_frames/ExoRun_blended.gif

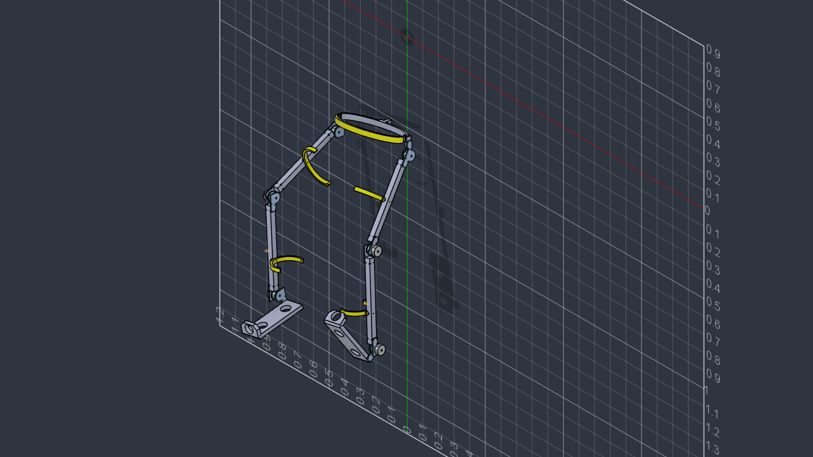
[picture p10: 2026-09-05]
ExoWalk_frames/frame_027.png

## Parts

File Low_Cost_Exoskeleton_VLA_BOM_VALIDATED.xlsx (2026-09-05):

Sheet: Low-Cost BOM
Low-Cost Exoskeleton Electronics + VLA Prototype |  |  |  |  |  |  | Validation against Motor Torque Analysis v2
Budget version for a bench / unloaded one-leg prototype. Existing ESP32, ESP32-CAM and laptop are counted at ₹0. |  |  |  |  |  |  | PDF basis: 80 kg reference case; knee 120 N·m peak / 60 N·m continuous, ankle 60 N·m peak / 30 N·m continuous, passive hip.
Item | Qty | Recommended specification | Approx. unit price (₹) | Est. total (₹) | Need now? | Notes | PDF requirement / check | Validation | Required correction / comment
Knee actuator | 1 | MY1016Z3, 24 V, 350 W geared brushed DC motor, about 300 RPM output; use extra chain/belt reduction for joint torque. | ₹3450 | ₹3450 | Yes | Cheap prototype motor only — not a final human-load actuator. | Knee: 120 N·m peak, 60 N·m continuous; provisional final drive is 48 V BLDC/PMSM, 300–400 W class. | CONDITIONAL | The 24 V 350 W brushed geared motor is not compliant with the PDF's final 48 V BLDC/PMSM recommendation. It can be used for bench/unloaded proof-of-concept only. External reduction must be much higher than 3:1–5:1.
Ankle actuator | 1 | MY1016Z3, 24 V, 350 W geared brushed DC motor, about 300 RPM output; use extra chain/belt reduction. | ₹3450 | ₹3450 | Yes | Suitable for bench/unloaded testing. | Ankle: 60 N·m peak, 30 N·m continuous; provisional final drive is 48 V BLDC/PMSM, 150–250 W class; keep distal mass low. | CONDITIONAL | 350 W is enough in power class, but this motor is heavy for the ankle and not the PDF's final BLDC/PMSM architecture. Use for bench/unloaded testing only.
Motor driver | 2 | BTS7960 dual H-bridge module, about 43 A peak module rating, 6–27 V motor supply, ESP32-compatible PWM logic. | ₹309 | ₹618 | Yes | One driver per motor. | Motor control must allow reversible joint actuation and safe current limiting. | CONDITIONAL | BTS7960 modules can be used for a cheap bench prototype, but verify real thermal/current performance. The BTS7960 IC is obsolete; do not treat the advertised 43 A as a guaranteed continuous module current.
Main controller | 1 | ESP32 DevKit / ESP32-WROOM-32. | ₹0 | ₹0 | Already available | Use for PWM, sensors, watchdog and safety checks. | Controller must implement commanded knee/ankle outputs; hip remains passive. | PASS | ESP32 is appropriate as a low-level prototype controller for PWM, encoder reading, watchdog and limits.
Camera | 1 | ESP32-CAM with OV2640 camera. | ₹0 | ₹0 | Already available | Use as low-cost vision / logging camera. | Camera is not part of torque sizing. | PASS FOR PROTOTYPE | ESP32-CAM is fine to prove the VLA/CV pipeline, but it is not a final high-quality perception sensor.
VLA computer | 1 | Existing laptop or desktop PC with Python/PyTorch; GPU preferred but not required for initial control tests. | ₹0 | ₹0 | Already available | Avoid buying a Jetson during early development. | VLA compute is outside the mechanical torque model. | PASS | Using the existing laptop is the cheapest sensible choice for early VLA development.
Joint encoder | 2 | AS5600 12-bit magnetic absolute angle sensor. | ₹175 | ₹350 | Yes | One at knee and one at ankle. | Loaded joint angle / velocity must be measured for final sizing and validation. | PASS | AS5600 joint encoders directly support joint-angle measurement. Calibrate joint zero and sign.
IMU | 3 | MPU6050 6-axis IMU (3-axis accelerometer + 3-axis gyroscope). | ₹144 | ₹432 | Yes | Start with pelvis, thigh and shank. | Loaded motion / body-segment state should be recorded; PDF requires loaded joint kinematics. | CONDITIONAL | Three MPU6050 boards are useful, but multiple I²C devices need proper bus addressing. Add an I²C multiplexer or separate buses.
Foot pressure sensor | 4 | FSR402 or similar force-sensitive resistor. | ₹150 | ₹600 | Yes | Place at heel, toe, medial forefoot and lateral forefoot. | PDF requires synchronized ground-reaction force and centre-of-pressure trajectories for final sizing. | PARTIAL | Four FSRs can estimate contact timing and rough COP only. They are not a replacement for calibrated force-plate/GRF data.
ADC | 1 | ADS1115, 16-bit, 4-channel ADC module. | ₹200 | ₹200 | Yes | Reads the four pressure sensors with better resolution. | Pressure sensors require synchronized acquisition. | PASS | ADS1115 can read four FSR channels for prototype logging. Confirm configured sample rate is sufficient for the chosen gait experiment.
Bench power supply | 1 | 24 V, 40 A (about 960 W) SMPS for simultaneous knee + ankle bench testing; a 20 A supply is only suitable if testing one motor at a time. | ₹4500 | ₹4500 | Yes | For early bench testing only; use guarded setup and proper fusing. | Power must support the loaded motor duty cycle; final current and thermal validation are required. | CONDITIONAL | For simultaneous knee + ankle operation, use about a 24 V / 40 A-class bench supply or test one motor at a time. Final supply sizing must be confirmed from measured current.
Emergency stop | 1 | Mushroom-type E-stop switch, preferably 1NO + 1NC. | ₹600 | ₹600 | Yes | Should remove motor power independently of software. | PDF requires emergency braking and power-loss support strategy. | PARTIAL | An E-stop switch alone should not carry motor current. Add a DC-rated contactor/relay so the E-stop physically removes motor power.
Main fuse + holder | 1 | DC-rated fuse and holder suitable for a 24 V prototype; choose current rating after measuring motor current. | ₹500 | ₹500 | Yes | Do not omit this. | Electrical protection is required before loaded bench validation. | PASS WITH SIZING | Keep the fuse, but size it from measured bus current and wire rating, not only from motor nameplate power.
24 V → 5 V buck converter | 1 | Regulated 24 V → 5 V, 3–5 A buck converter. | ₹250 | ₹250 | Yes | Powers ESP32, ESP32-CAM and small sensors. | Logic supply must be isolated from motor-current disturbances as much as practical. | PASS | 24 V → 5 V buck is suitable for ESP32/camera/sensors if rated for noise and current.
Chain / belt reduction kit | 2 | Knee: target about 15:1 external reduction. Ankle: target about 25:1 external reduction. Use a two-stage chain/belt reduction if needed; limit commanded torque in software. | ₹1500 | ₹3000 | Yes | One reduction stage per powered joint. | Transmission must deliver the required joint torque while preserving required joint speed. | FAIL AS WRITTEN | 3:1–5:1 is too small. The PDF gait reaches about 19.2 rpm at the knee and 11.0 rpm at the ankle. With a ~300 rpm geared motor output, speed-matched starting ratios are about 15–16:1 knee and 25–27:1 ankle. Validate actual torque, temperature and speed on a rig before loaded use.
Wires + connectors | 1 | Motor wire, signal wire, XT60/terminal connectors, ferrules, heat-shrink and cable ties. | ₹1000 | ₹1000 | Yes | Use thicker wire for motor-current paths. | Wiring must tolerate motor current and sensor wiring should be separated from high-current paths. | PASS WITH SIZING | Keep this row; choose conductor gauge/connectors after current tests and add strain relief.
Estimated one-leg prototype total |  |  |  | ₹18950 | Approximate only — re-check seller prices before purchase.
Important: this low-cost motor setup is for bench, suspended-leg or unloaded control/VLA experiments. It is not a substitute for the final actuators required for the full exoskeleton torque targets.
Additional required item | Qty | Recommended specification | Approx. unit price (₹) | Est. total (₹) | Need now? | Notes
I²C multiplexer | 1 | TCA9548A 8-channel I²C multiplexer module. | ₹250 | ₹250 | Yes | Needed to cleanly connect multiple AS5600 and MPU6050 devices that share/fix I²C addresses.
DC motor power contactor / relay | 1 | 24 V DC coil, DC-rated contactor/relay, at least 60 A contact rating for bench prototype. | ₹1500 | ₹1500 | Yes | E-stop controls the coil; contactor physically removes motor power.

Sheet: Budget Summary
Budget Summary
Prototype | Estimated cost (₹)
One-leg low-cost prototype | ₹18950
Add second leg later | ₹11594
Approx. two-leg low-cost hardware | ₹30544
Existing ESP32 + ESP32-CAM + laptop | ₹0
What is intentionally removed from this budget?
CubeMars integrated actuators
Jetson Orin NX
RealSense D455
Research-grade inline torque sensors
CAN bus hardware
Validation update | Result / Budget
Original one-leg estimate | ₹18950
Validated corrections added | ₹1750
Revised one-leg estimate | ₹20700
Final wearable compliance | NO — bench/unloaded prototype only
Main reason | Cheap 24 V brushed motors do not match the PDF's provisional 48 V BLDC/PMSM final drive recommendation.
Required before human test | Instrumented dummy-load bench validation, final GRF/COP data, thermal/current validation and fail-safe power cut.
Verdict | Validated only as a low-cost bench/unloaded VLA prototype.
Not validated for | Human-weight-bearing operation using the current cheap motors/transmission.
Key corrections made | 24 V / 40 A supply, ~15:1 knee reduction, ~25:1 ankle reduction, I²C multiplexer, and hardware power contactor.

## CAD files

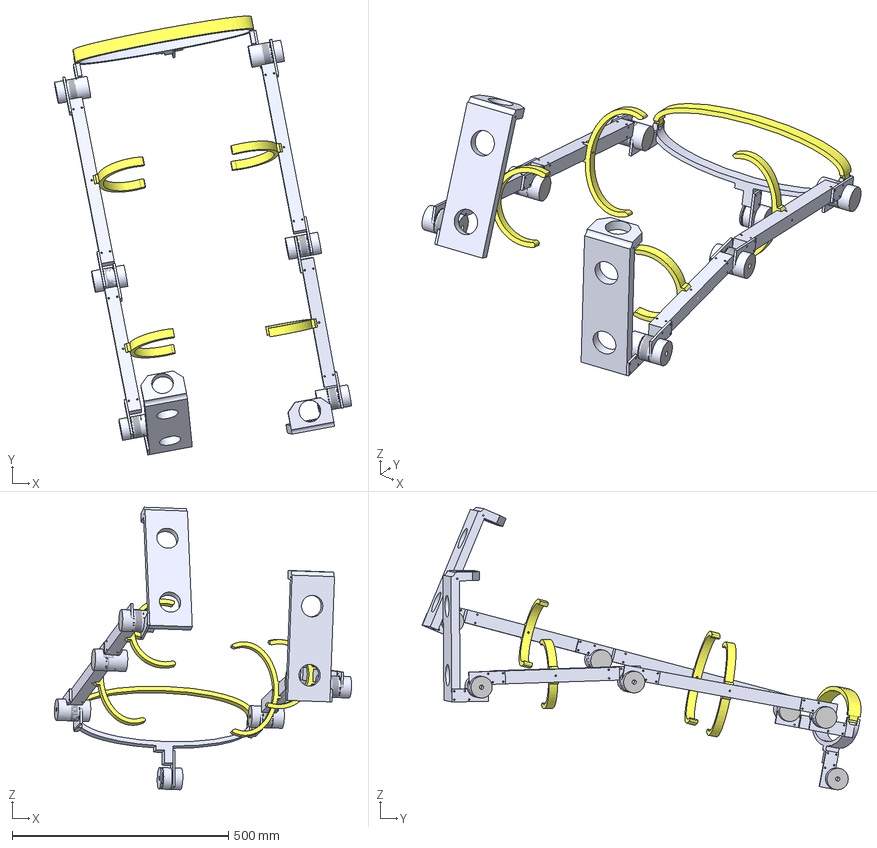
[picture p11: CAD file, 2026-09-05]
ExoEskeleto_final.step
687.4 x 1015.9 x 653.9 mm
Electroiman x 3
LaminaEjeMagnetico
Cinturon
LaminaEjeMagnetico_6 x 7
Bota
Electroiman_1
LaminaEjeMagnetico_1
LaminaEjeMagnetico_2
Ac40
Ac40_1
Ac30
Electroiman_2
LaminaEjeMagnetico_3
LaminaEjeMagnetico_4
Electroiman_3
Ac30_1
LaminaEjeMagnetico_5
Electroiman_4
Bota_1
Banda Cinturon
Banda Cinturon (1)
Banda Cinturon (2)
Banda Cinturon (3)
Banda Cinturon (4)
Cin1
Cin1_1
Cin2
Cin2_1

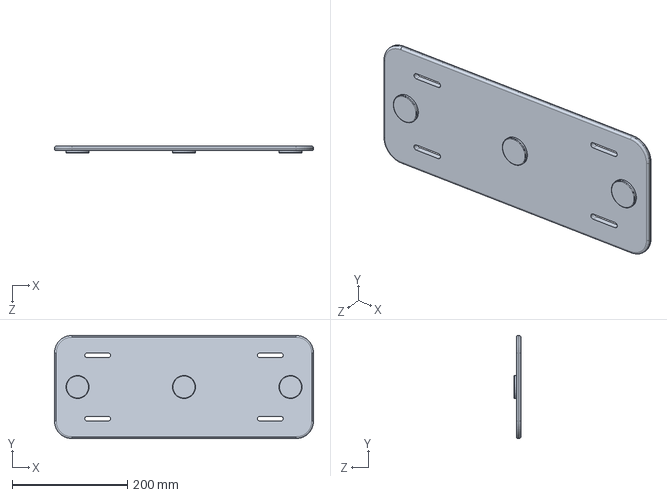
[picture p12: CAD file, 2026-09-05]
MOSAIC_HIP_SOLIDWORKS/PARTS/01_PELVIC_PLATE.SLDPRT
450.0 x 179.0 x 12.0 mm

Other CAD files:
MOSAIC_HIP_SOLIDWORKS/PARTS/02_HIP_MODULE_VISUAL.SLDPRT
MOSAIC_HIP_SOLIDWORKS/PARTS/Test.SLDPRT

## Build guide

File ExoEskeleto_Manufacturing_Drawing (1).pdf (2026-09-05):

# GENERAL NOTES, TOLERANCES & SPECIFICATION

# 1. GENERAL

1.1 All dimensions are in millimetres (mm).
1.2 Material: Aluminium 6061-T6 for all fabricated parts, unless noted. 1.3 Remove all burrs and break sharp edges 0.3 max.
1.4 Finish: clear anodise or powder-coat. Pad all body-contact surfaces. 1.5 Do not scale the drawing – work to stated dimensions.

# 2. TOLERANCES (unless otherwise stated)

# 2.1 General linear dimensions | ±0.5 mm 2.2 Holes, bores & hole-to-hole positions ... ±0.1 mm 2.3 Angular dimensions | ±0.5° 2.4 Bearing bores Ø50 | H8 2.5 Axle holes Ø10 | H9 2.6 Mounting holes Ø4 | clearance for M4 fasteners

# 3. HOLLOW SECTIONS

3.1 Rods Ac30 / Ac40: 30 x 30 x 3.5 mm wall square tube.
Procure as extruded tube – do NOT machine from solid.
3.2 Foot plates (Bota): 3.5 mm nominal wall – machine with tool access.

# 4. JOINTS & BEARINGS (all 6 joints identical)

4.1 Bearing bore Ø50.0 H8 in plate / cradle.

# 4.2 Joint hub outer Ø49.5 – gives 0.25 mm radial running

clearance (0.5 mm on diameter).
4.3 Fit a bronze bushing or ball bearing at the Ø50 interface; do not run bare aluminium on aluminium.

# 4.4 Axle: Ø10 H9 hole, use Ø9.8 shoulder bolt / dowel pin

with retention (nut or circlip).

# 4.5 Bearings, axles & fasteners are purchased standard parts

and are not shown on the part drawings.

# 5. KEY PARAMETERS

5.1 Total frame mass: 6.49 kg (excludes motors & hardware).
5.2 Thigh rod (Ac40) length 400 ; shank rod (Ac30) length 420. 5.3 Knee & ankle joints house the actuators; hips are passive pivots.
Created by | Approved by
varun akkena | 26-07-2026

### Title

# ExoEskeleto_final_with_measurements

## Sheet: Notes

1 A | 2 | 3 | 4 | 5 | 6 | 7 | 8 1 | 2 | 3 | 4 | 5 | 6 | 7 | 8 BCDEF | ABCDEF

# Parts List

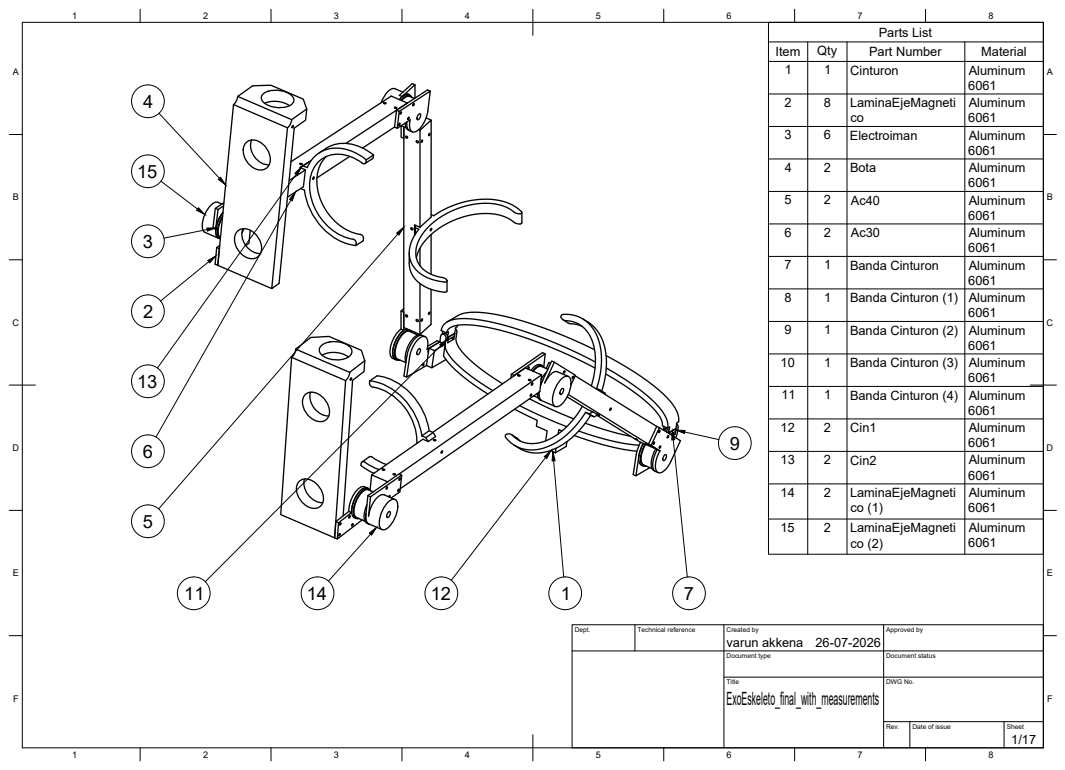
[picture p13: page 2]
Dept.; Technical reference; Created by; Approved by; Document type; Document status; Title; DWG No.; Rev.; Date of issue; Sheet; ExoEskeleto_final_with_measurements; varun akkena; Item; Qty; Part Number; Material 1; Cinturon; Aluminum; LaminaEjeMagneti; Electroiman; Bota; Banda Cinturon; Banda Cinturon (1); Banda Cinturon (2); Banda Cinturon (3); Banda Cinturon (4); Cin1; Cin2; Aluminum 6061

A

2 | 3 | 4 | 5 | 6 | 7 | 8

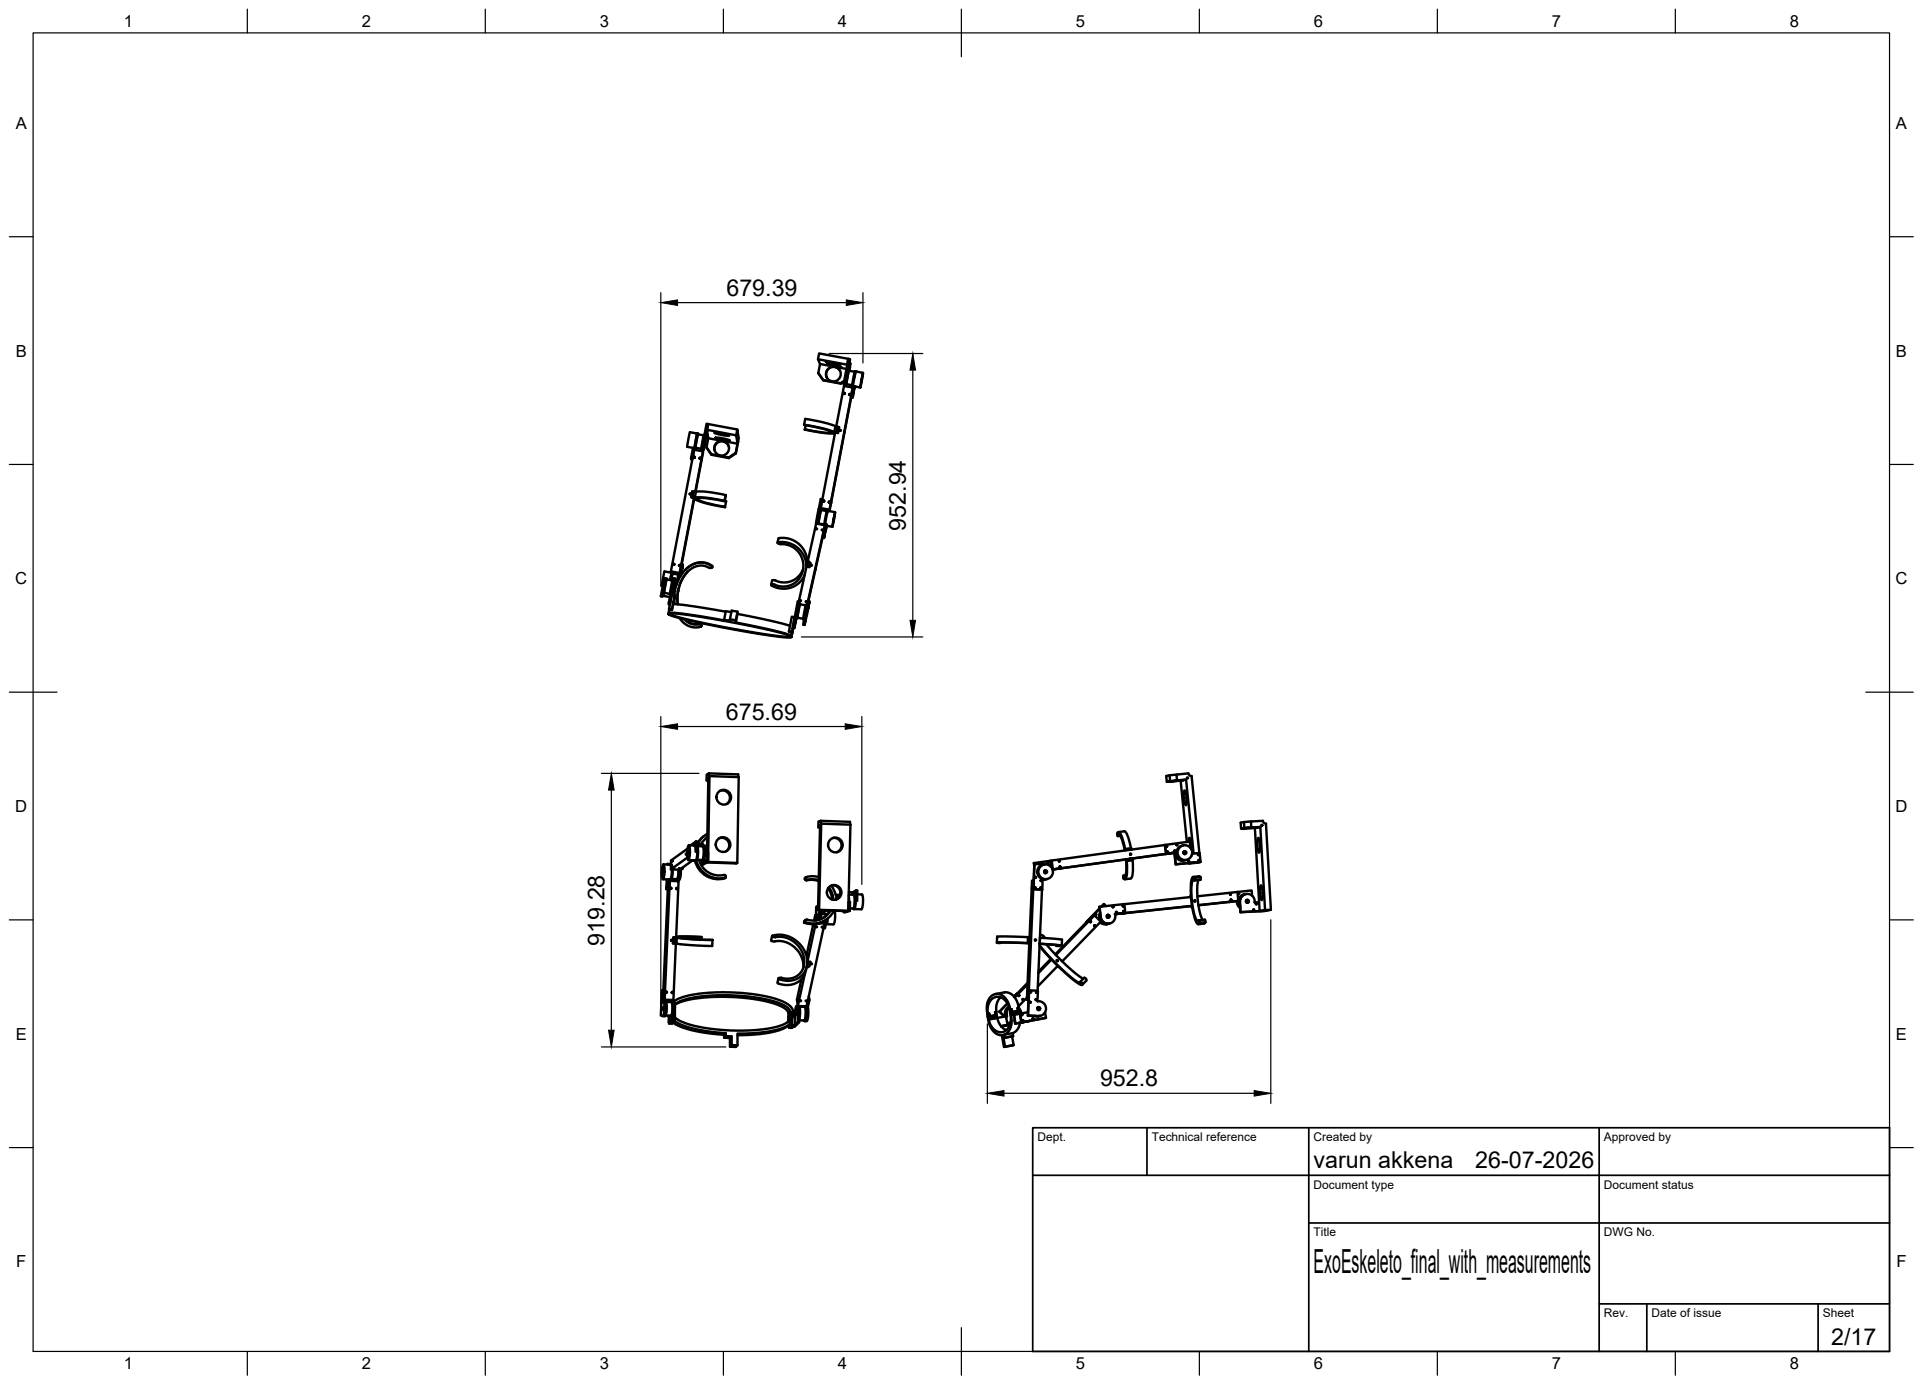
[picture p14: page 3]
Dept.; Technical reference; Created by; Approved by; Document type; Document status; Title; DWG No.; ExoEskeleto_final_with_measurements

varun akkena ⁹¹⁹.28

A

A

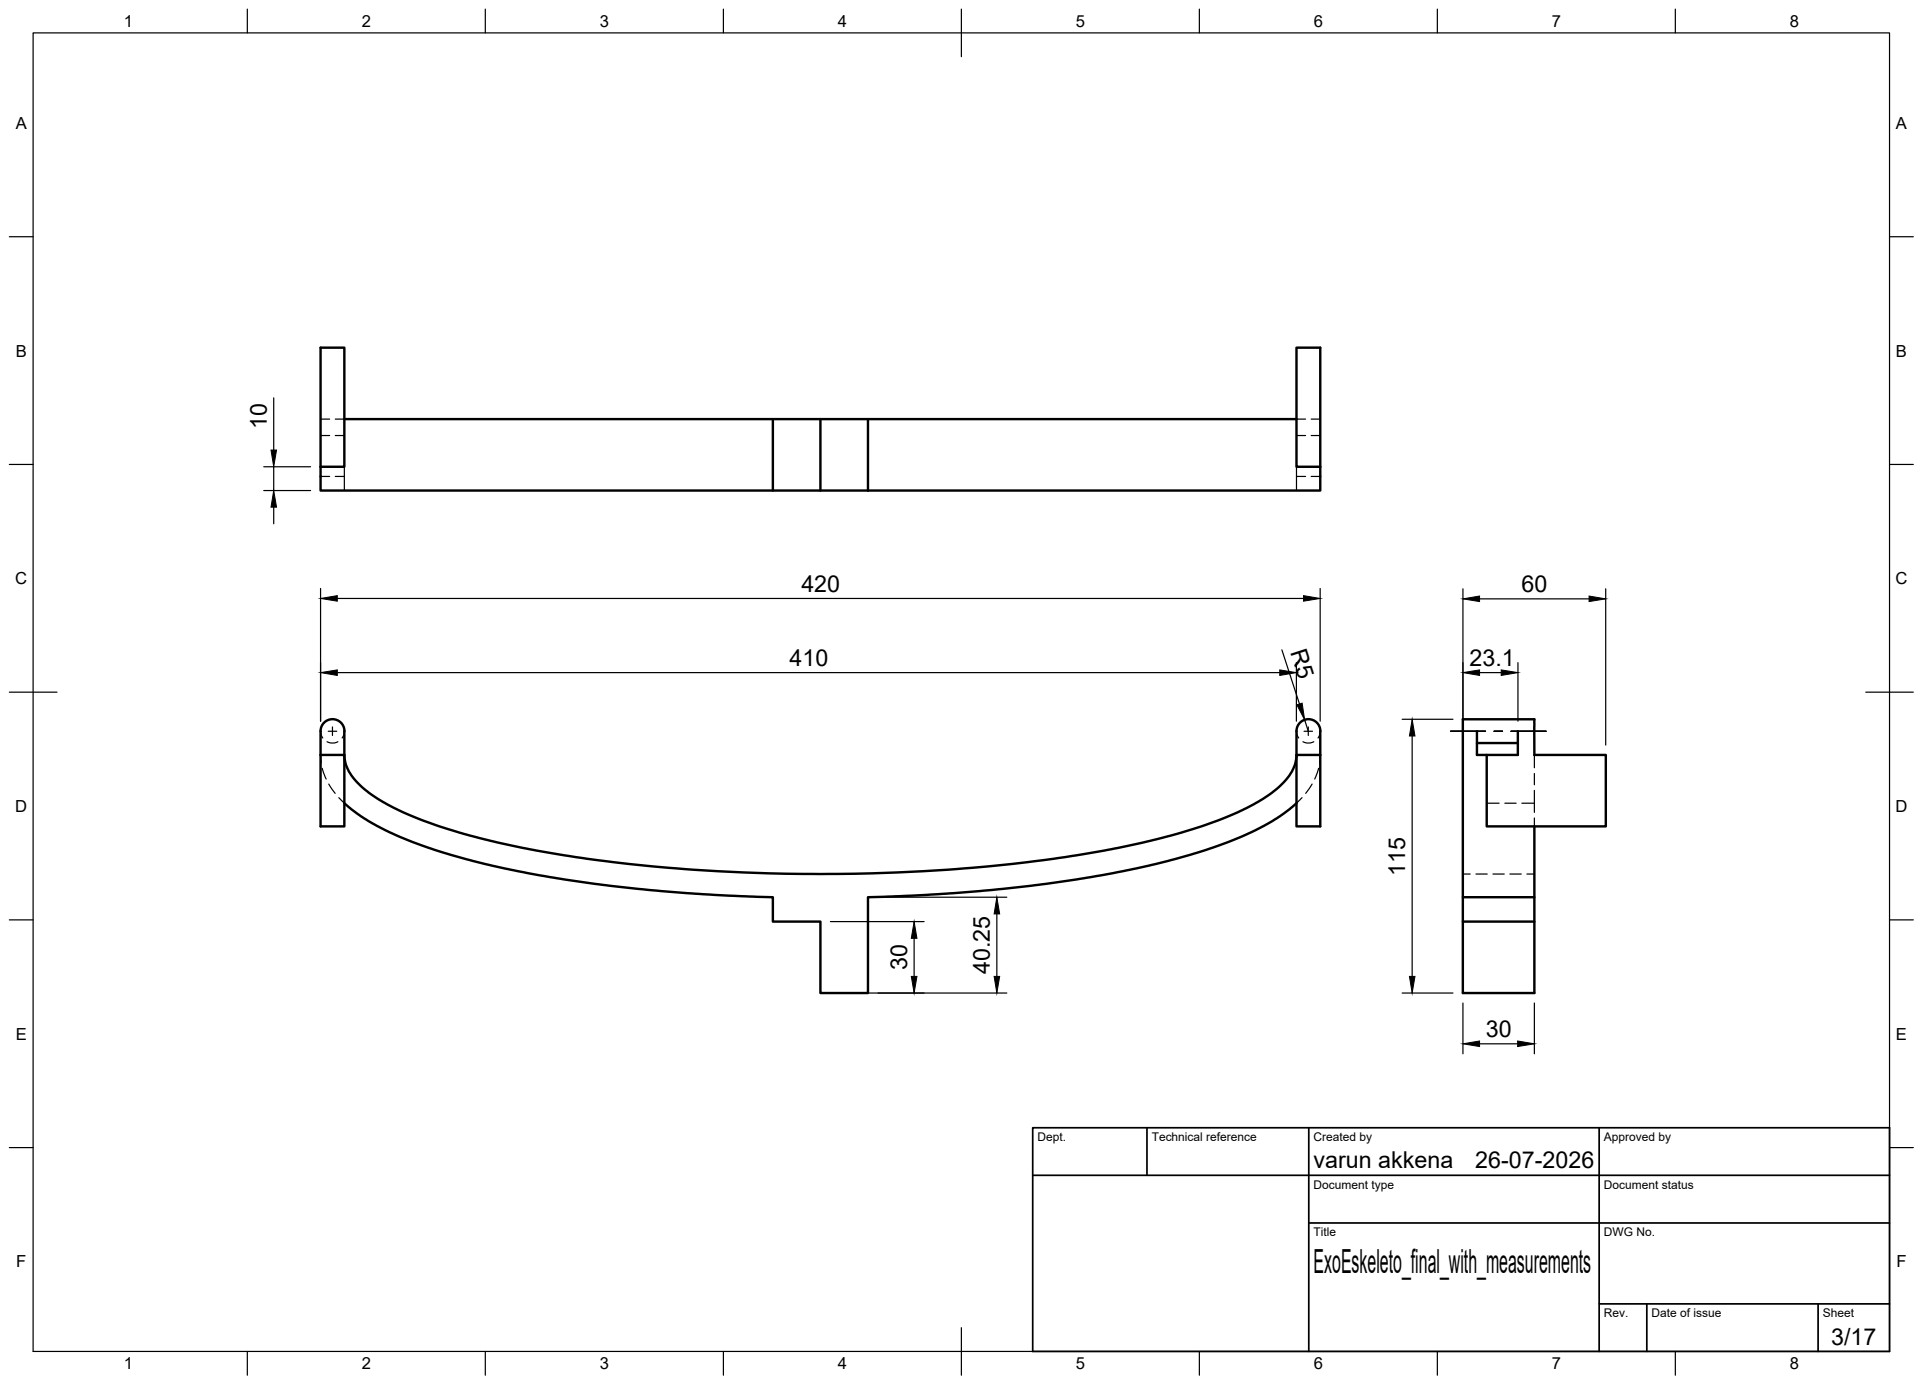
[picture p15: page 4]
Dept.; Technical reference; Created by; Approved by; Document type; Document status; Title; DWG No.; ExoEskeleto_final_with_measurements; varun akkena

A

A

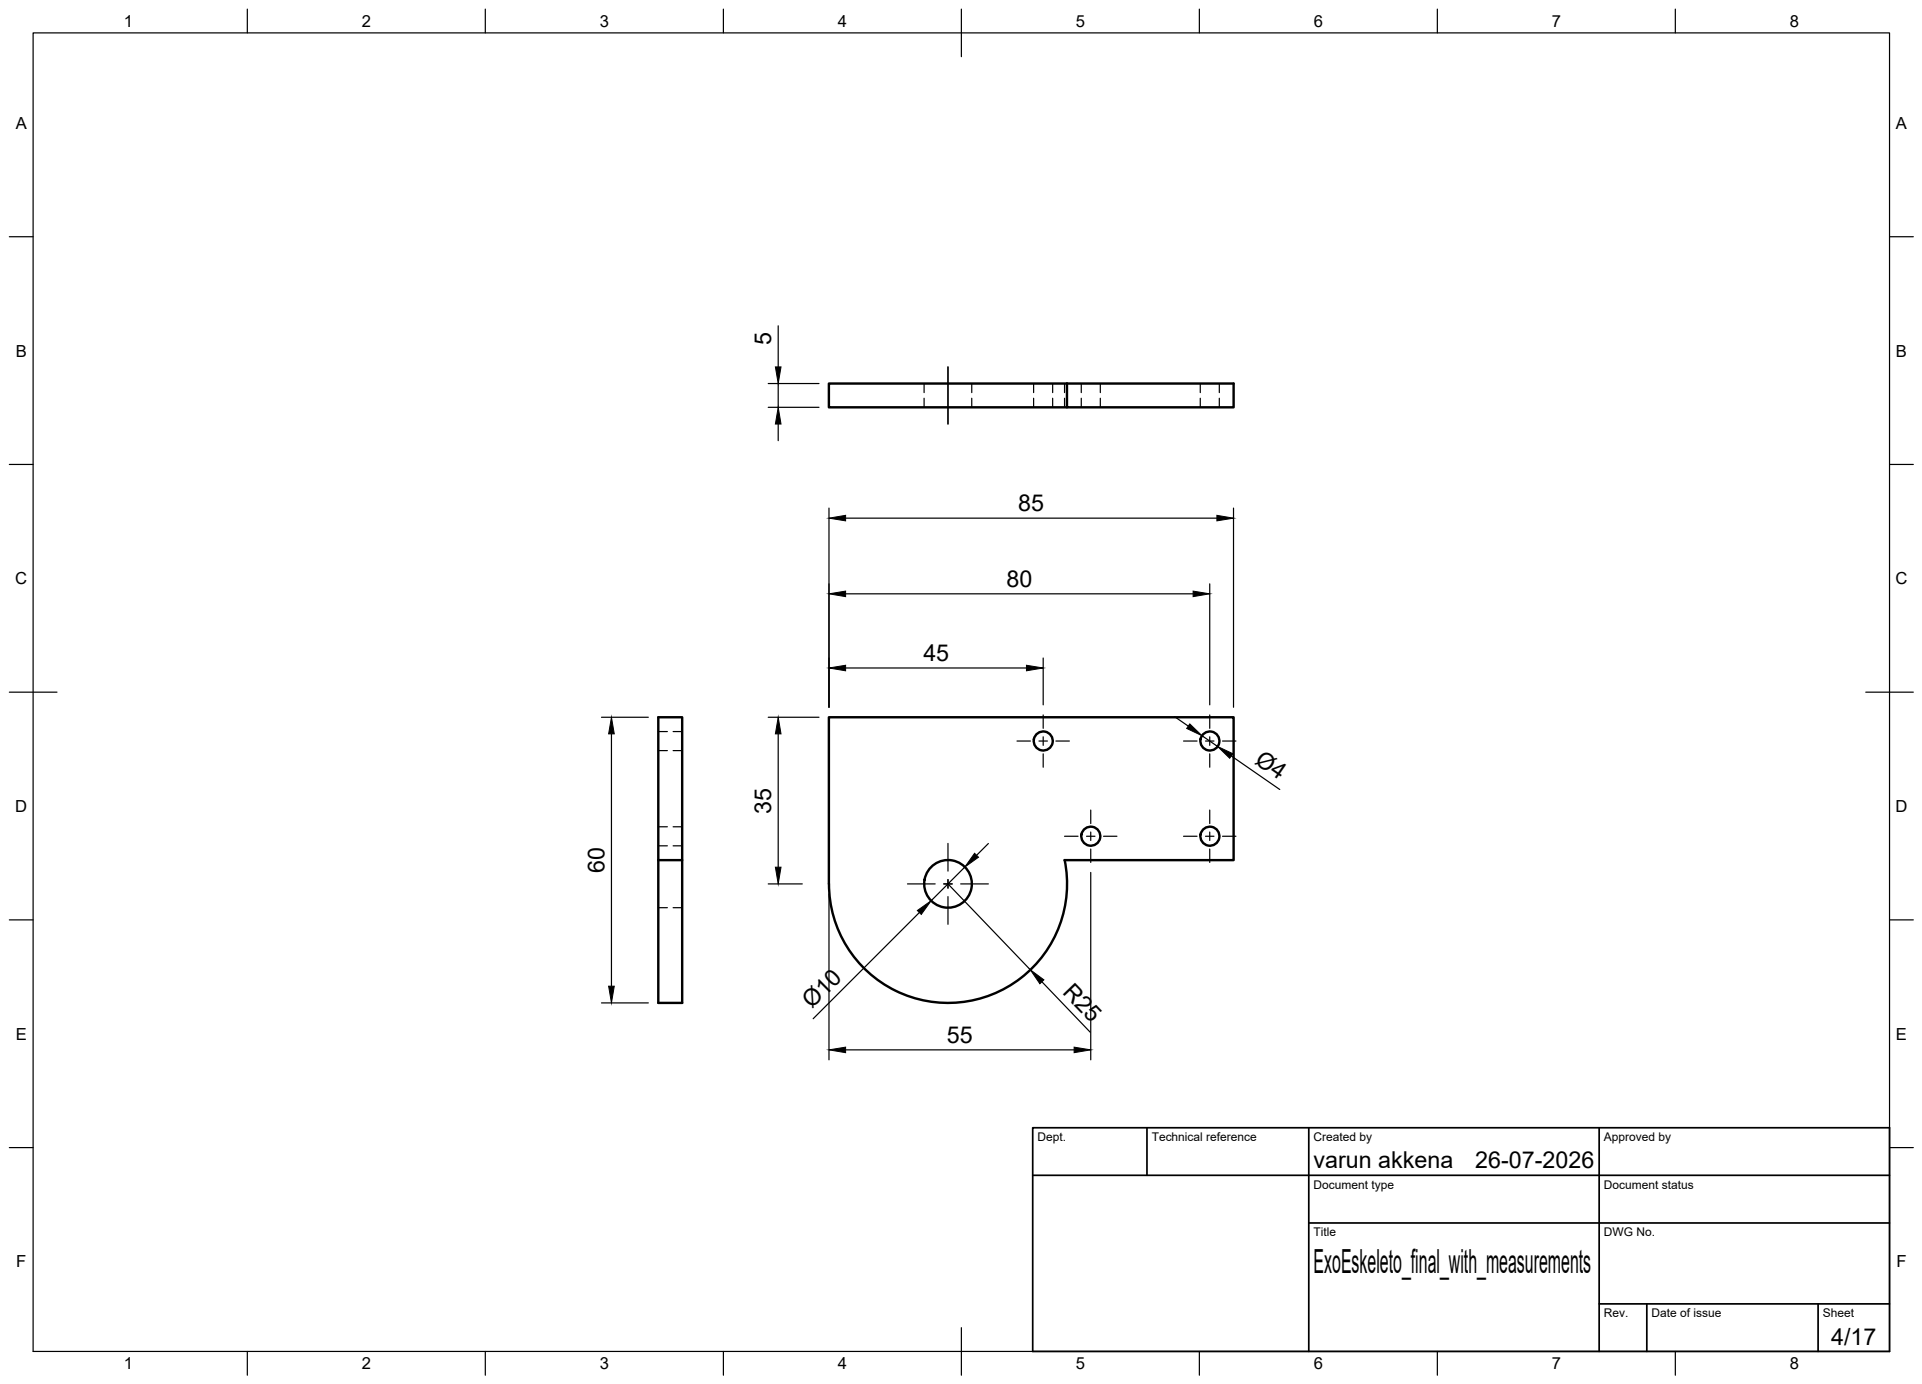
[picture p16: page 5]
Dept.; Technical reference; Created by; Approved by; Document type; Document status; Title; DWG No.; ExoEskeleto_final_with_measurements; varun akkena

A

A

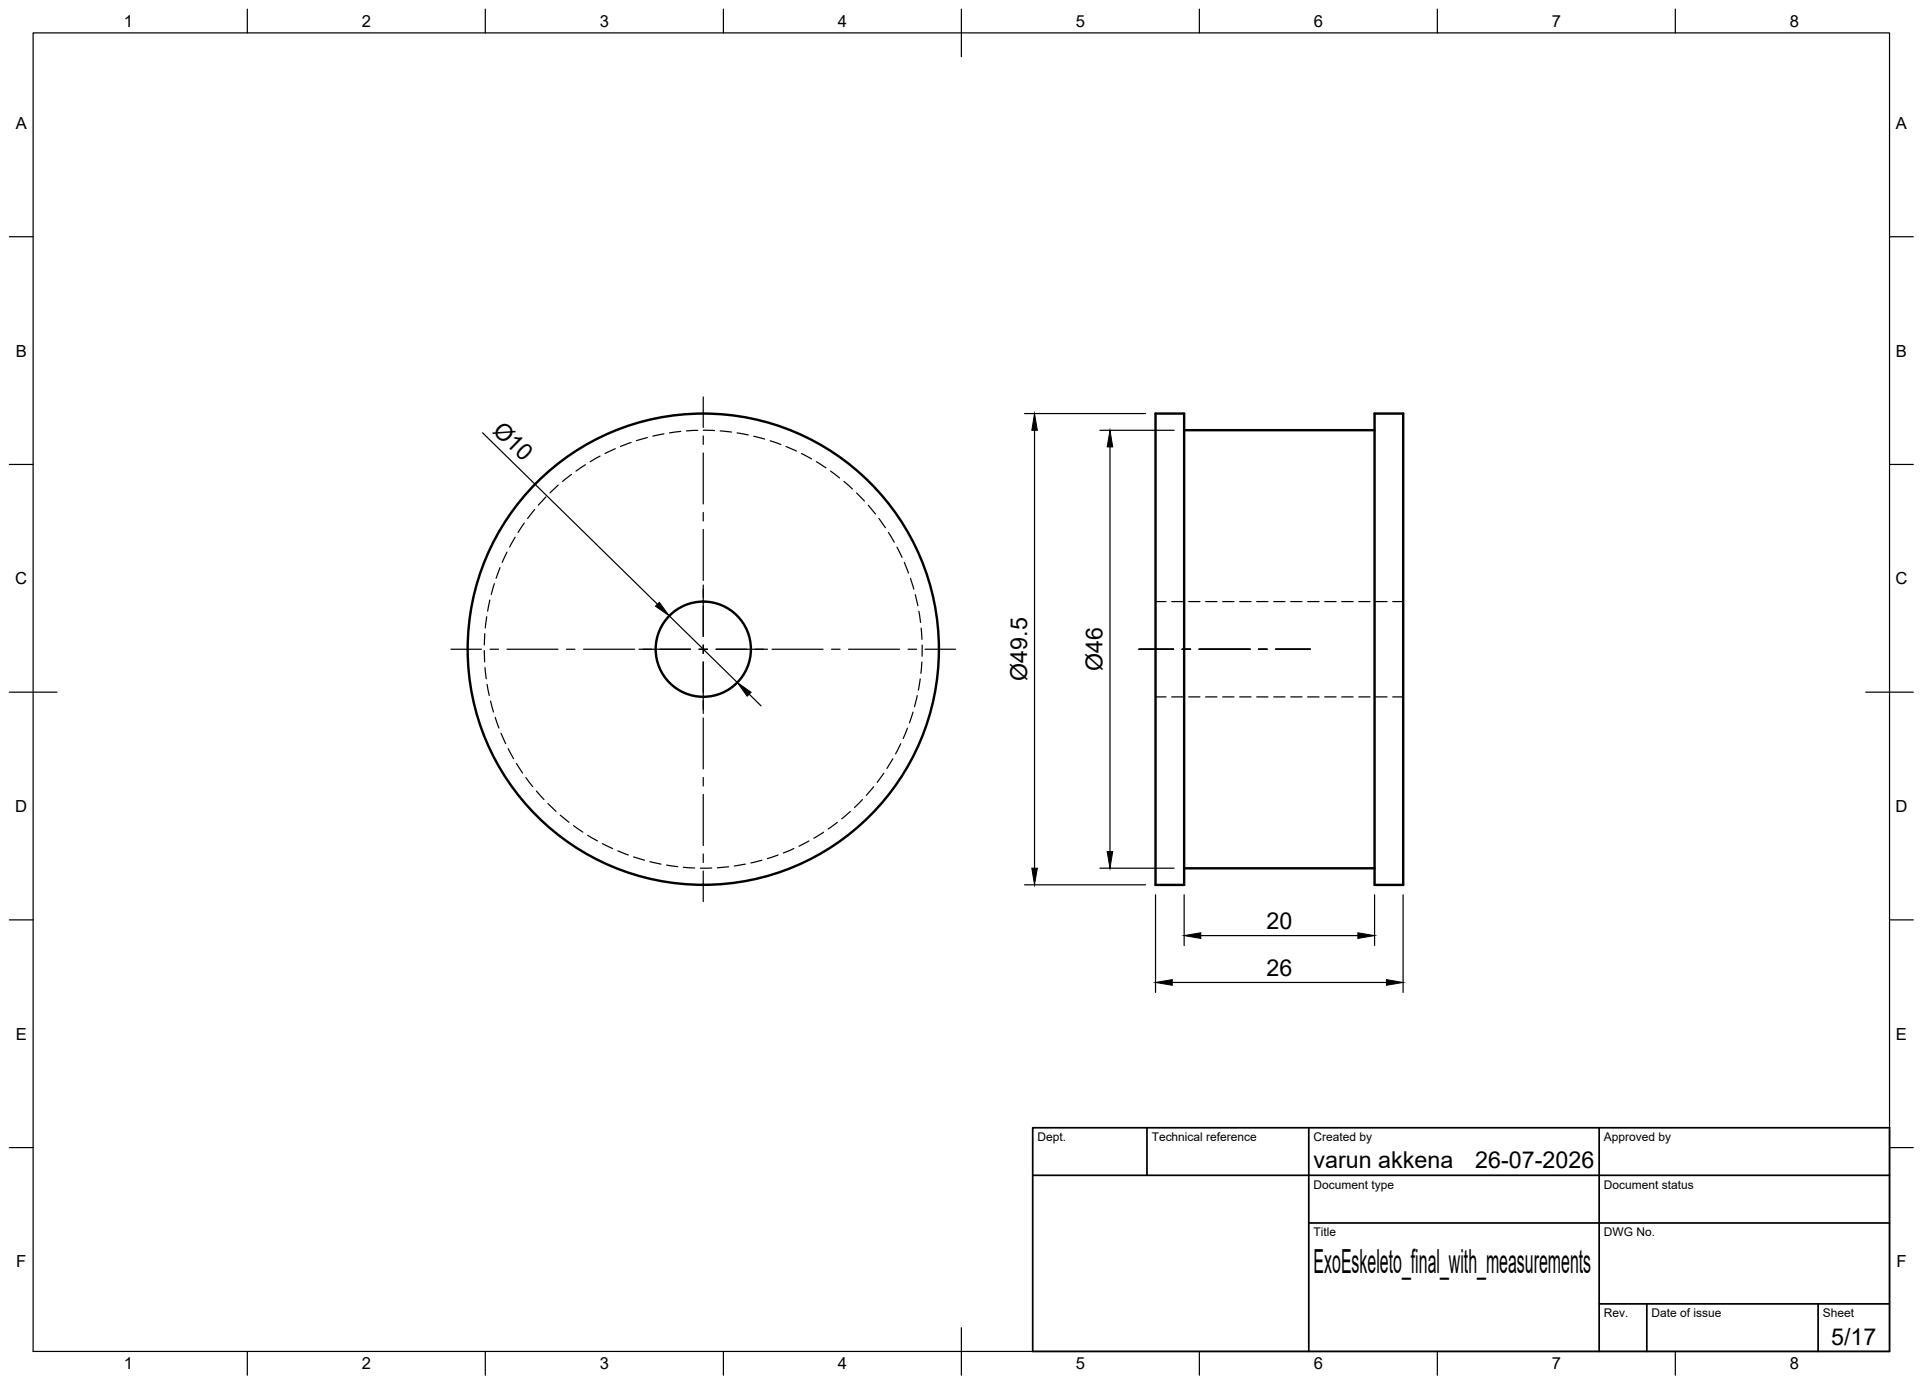
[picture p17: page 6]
Dept.; Technical reference; Created by; Approved by; Document type; Document status; Title; DWG No.; ExoEskeleto_final_with_measurements

varun akkena Ø⁴⁹.5

A

A

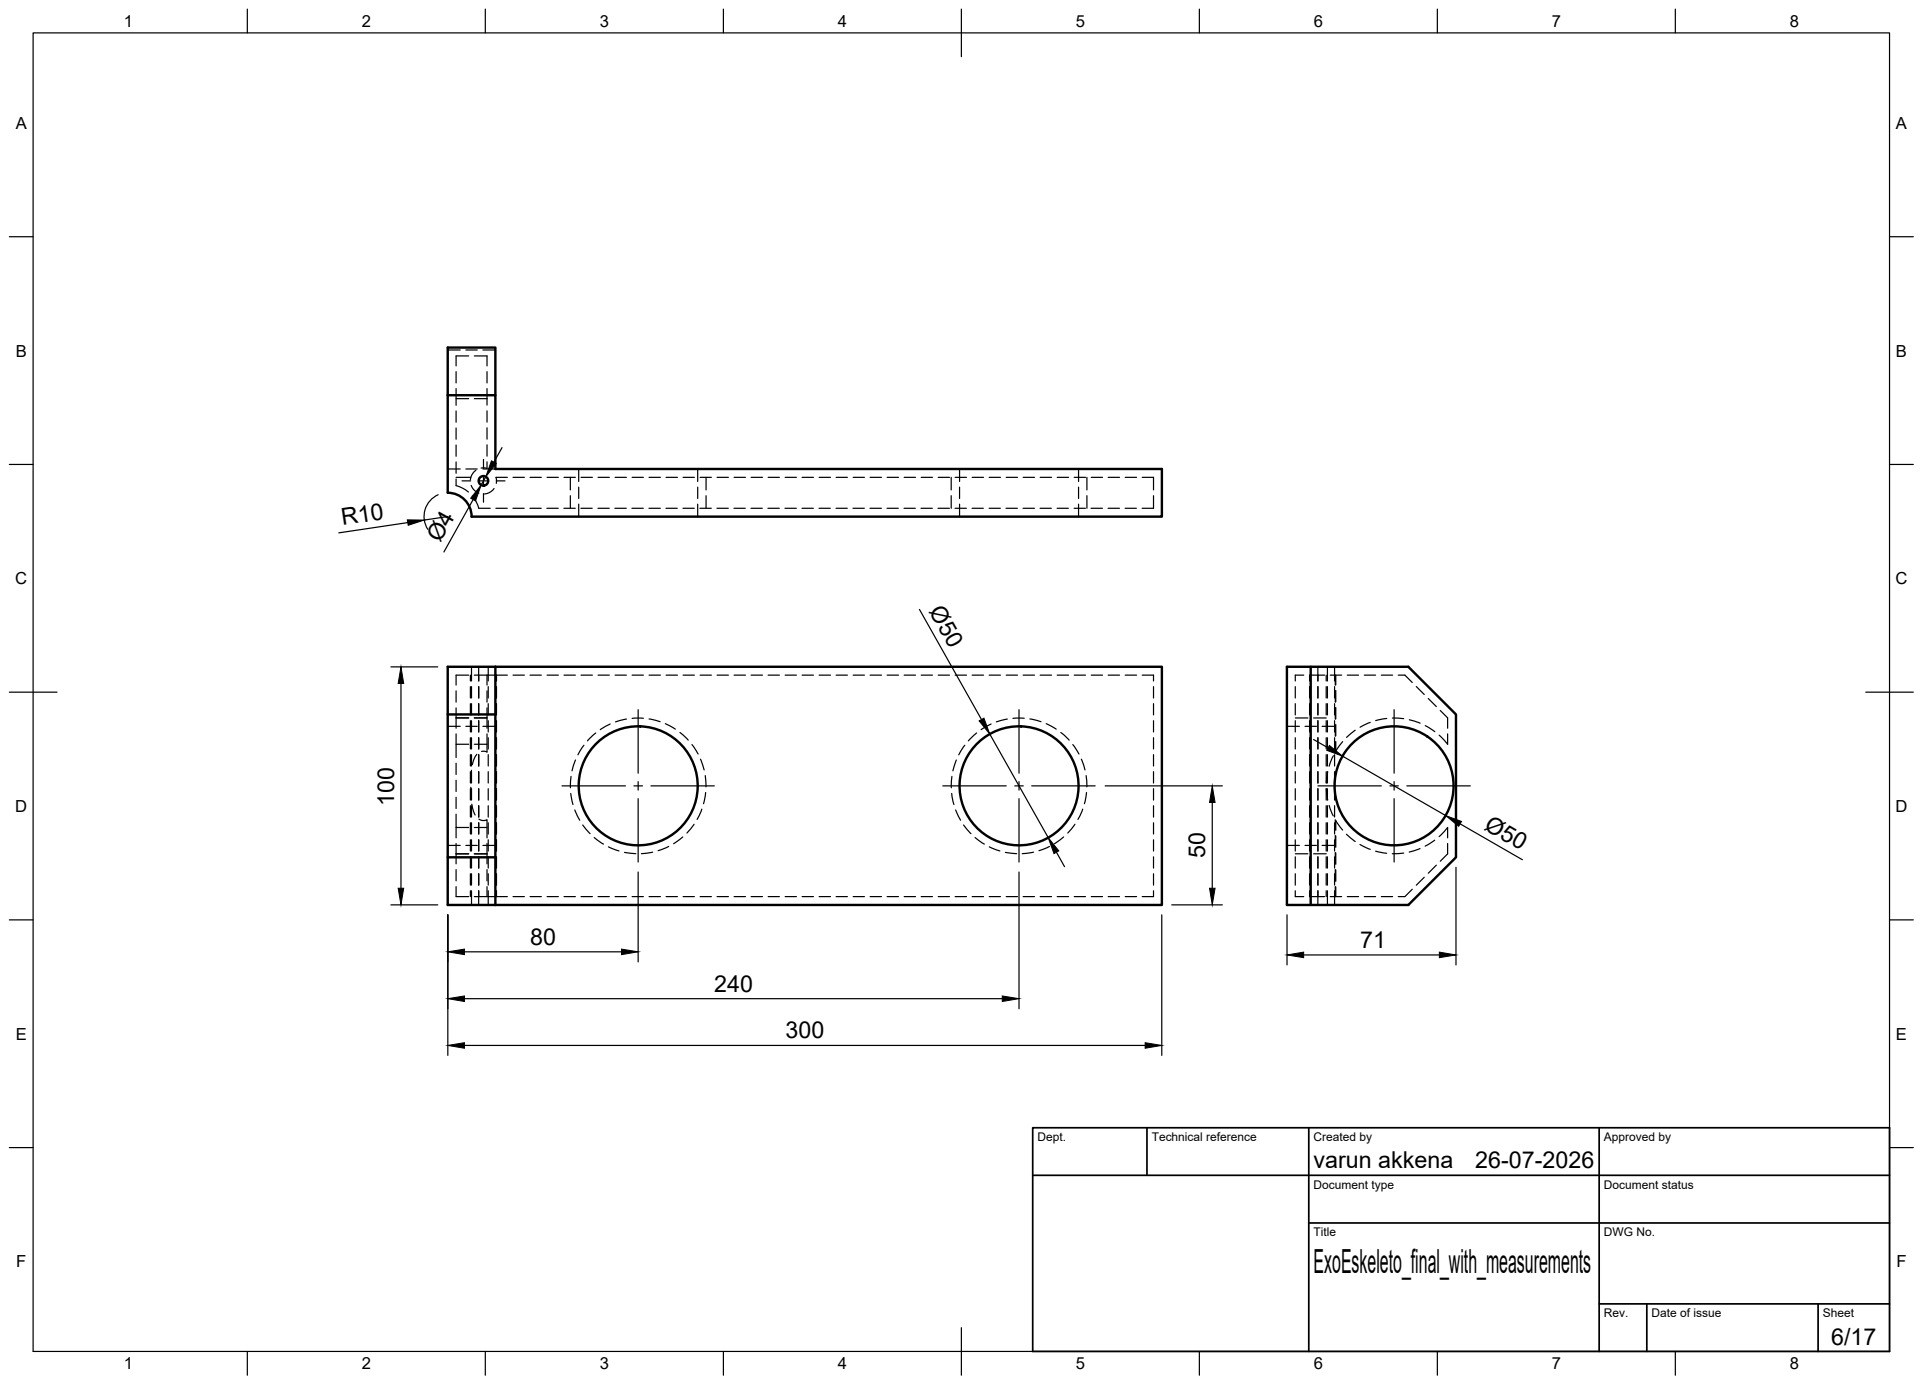
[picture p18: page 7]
Dept.; Technical reference; Created by; Approved by; Document type; Document status; Title; DWG No.; ExoEskeleto_final_with_measurements; varun akkena; 300 ¹⁰⁰

A

A

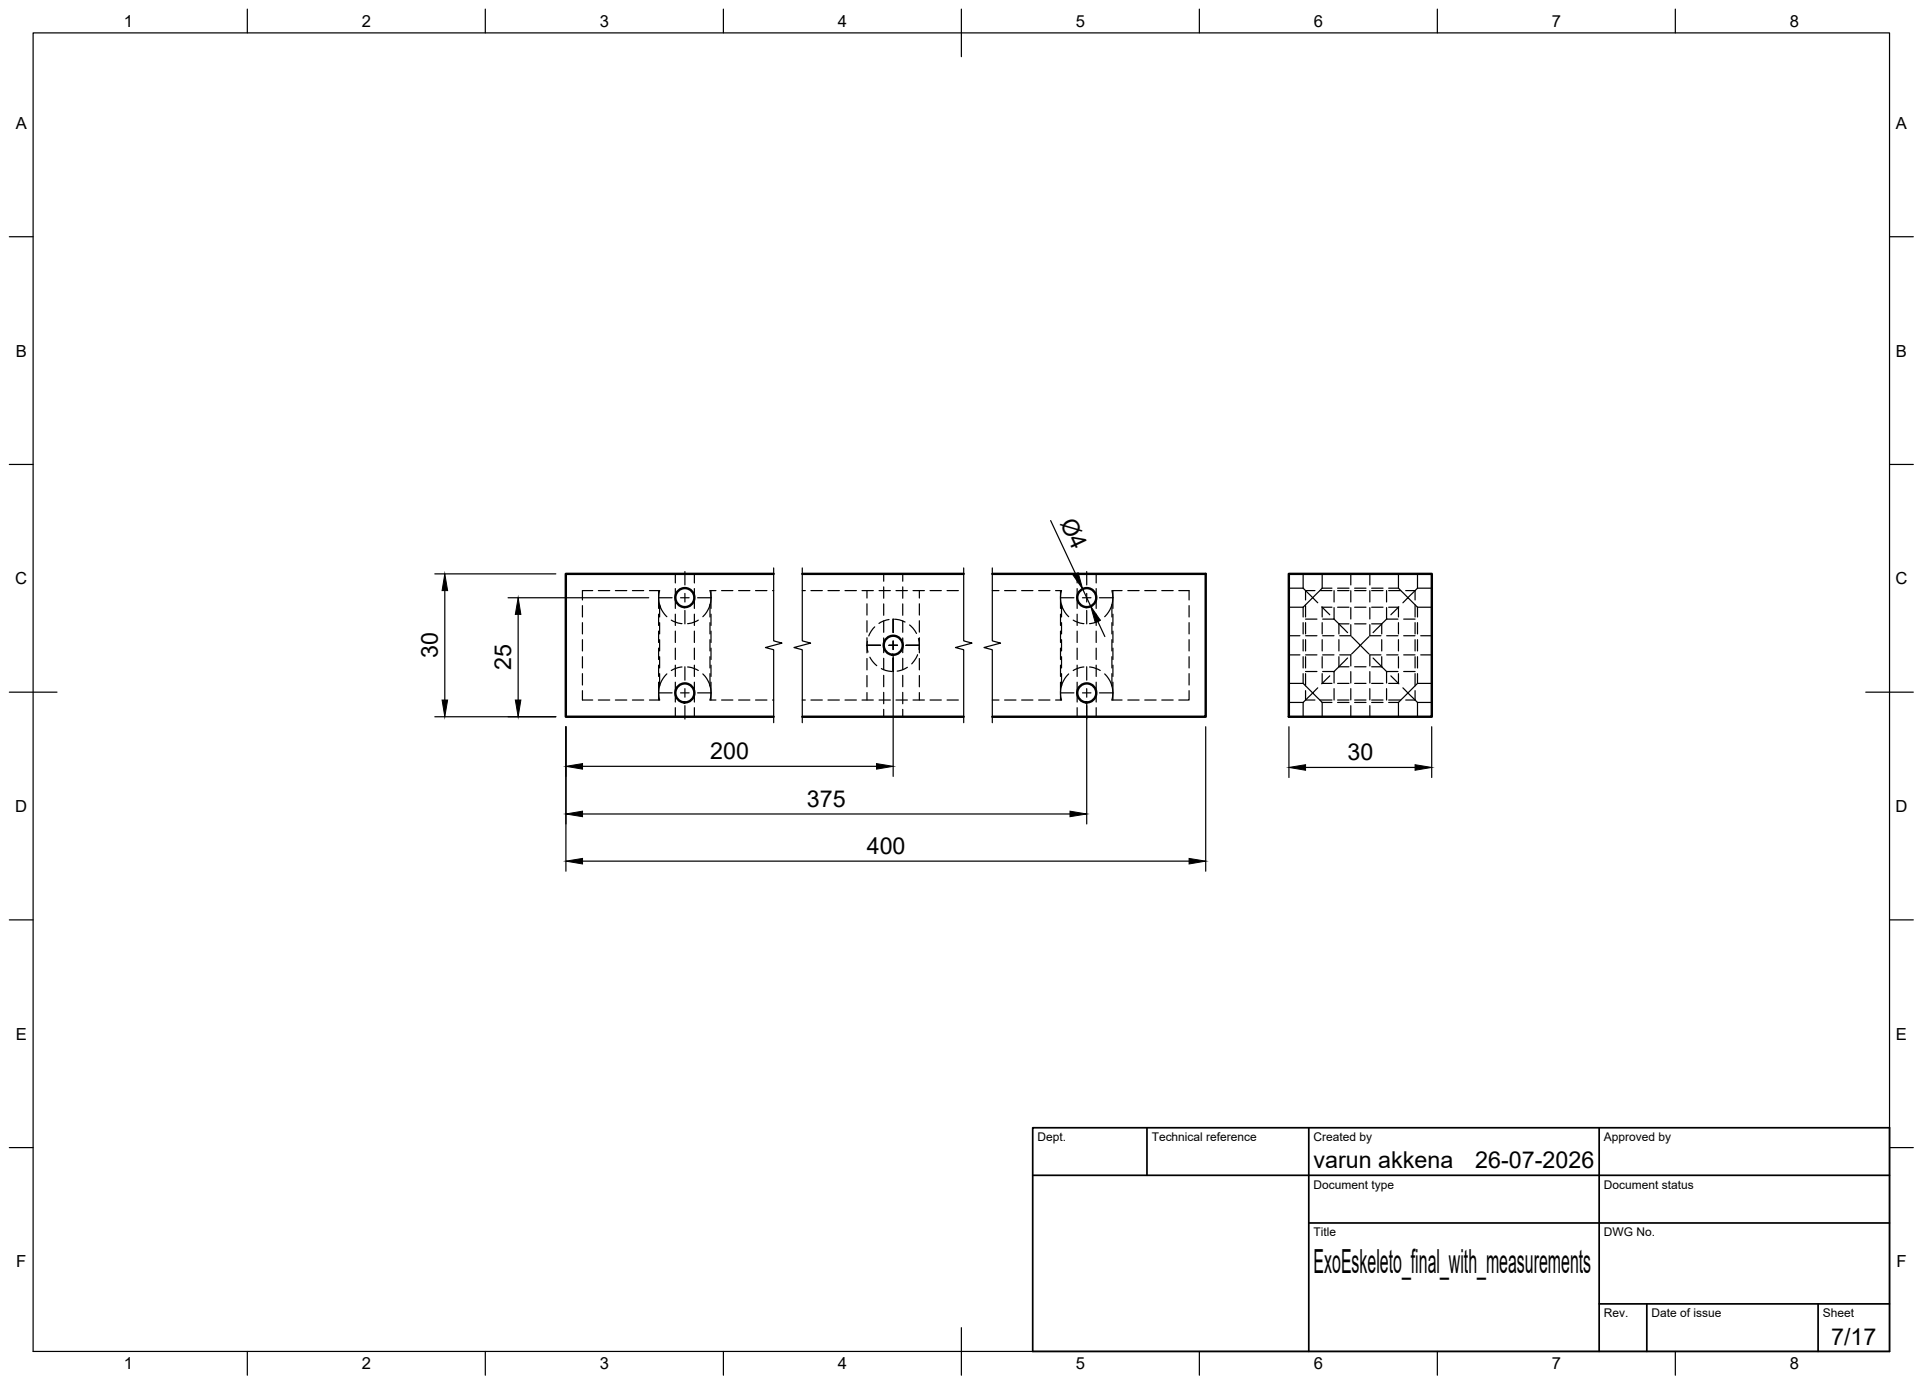
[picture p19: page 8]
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

A

A

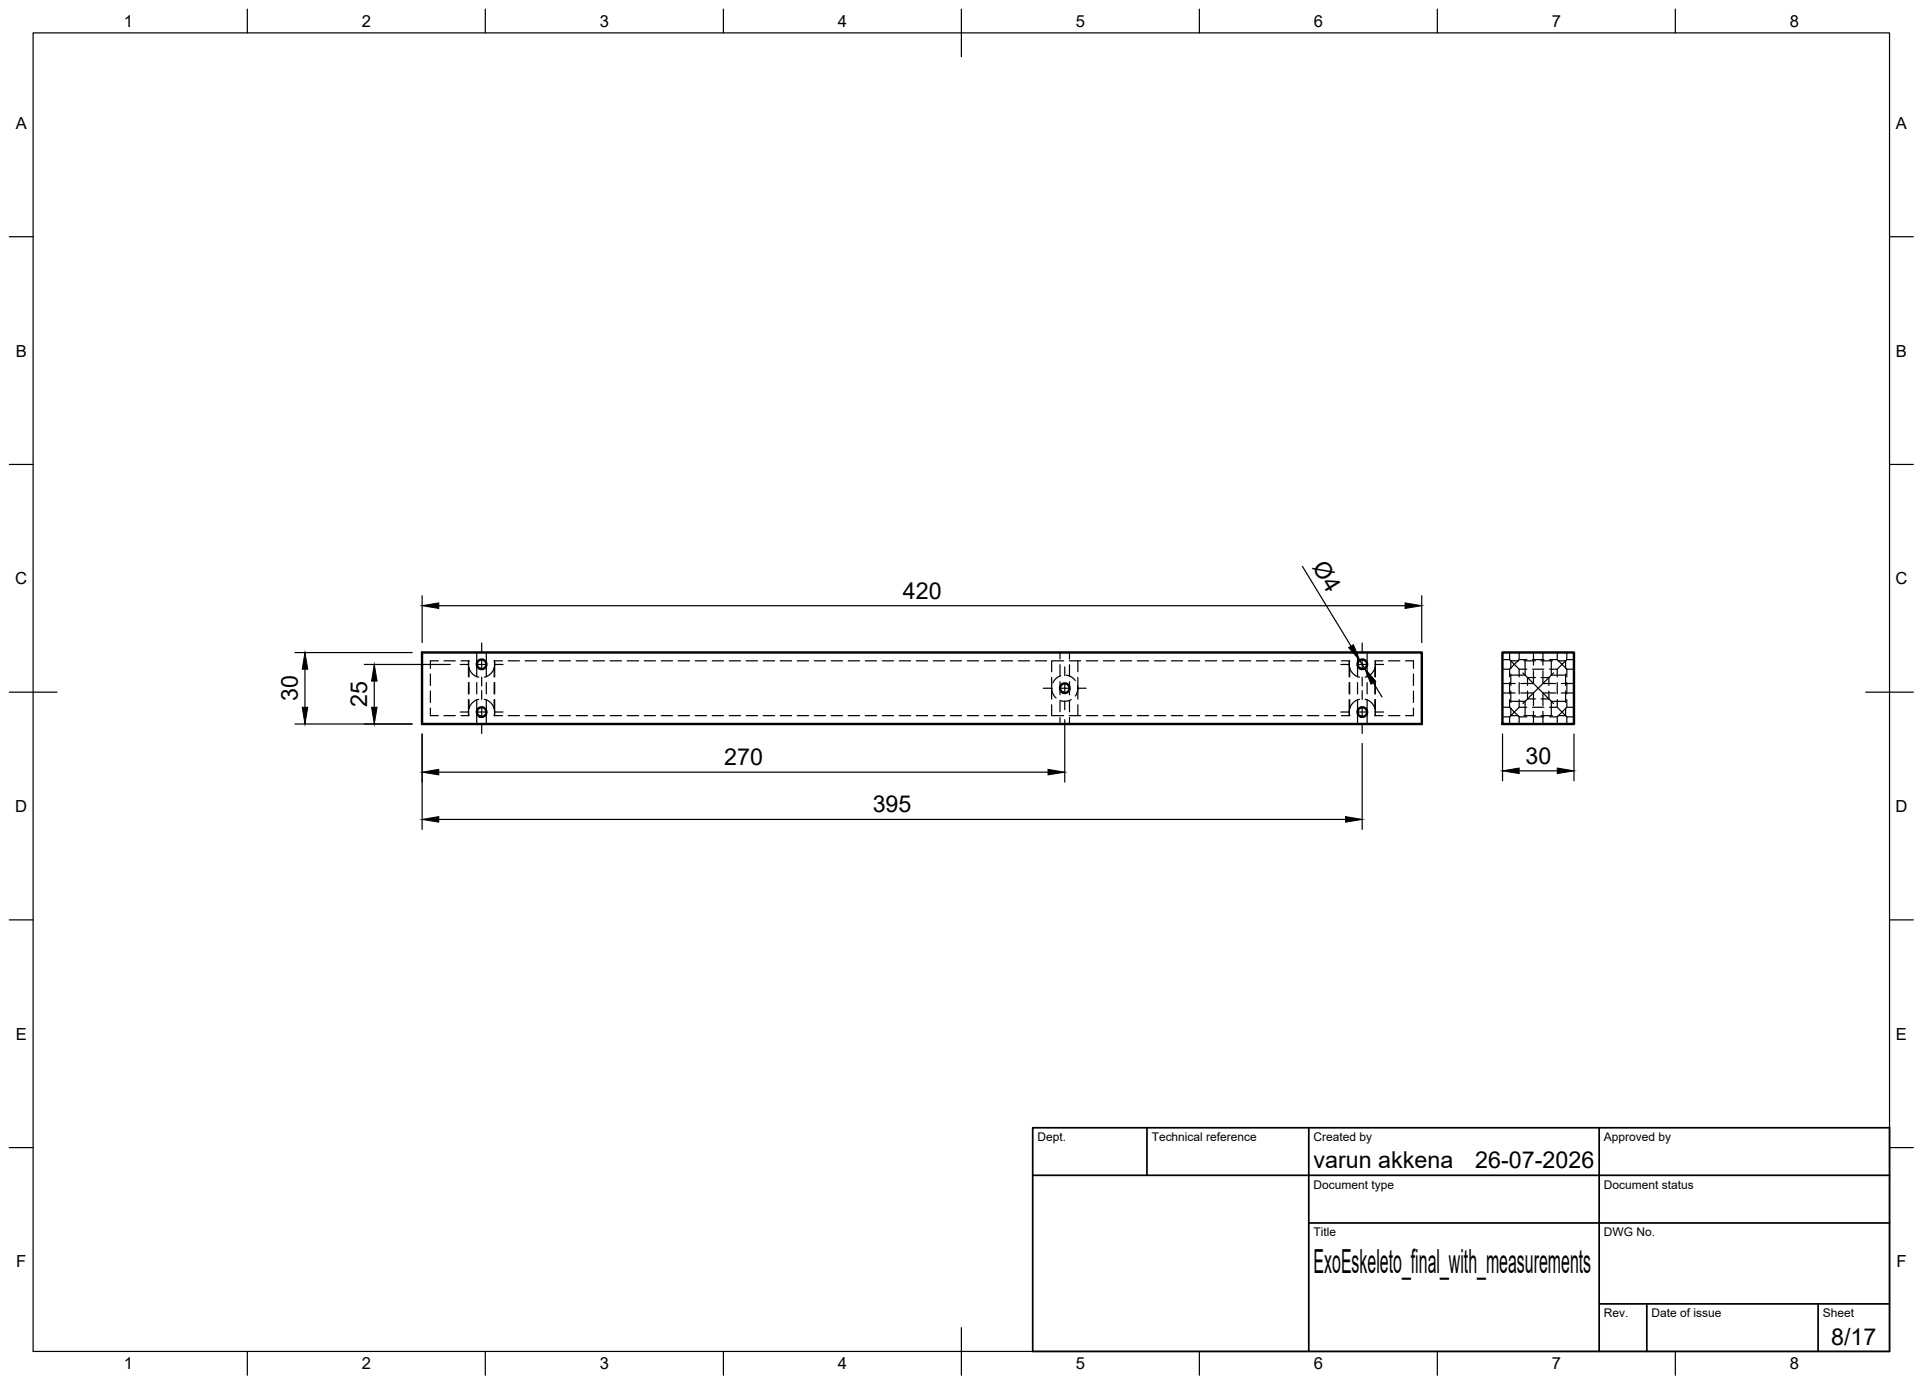
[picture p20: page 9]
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

A

A

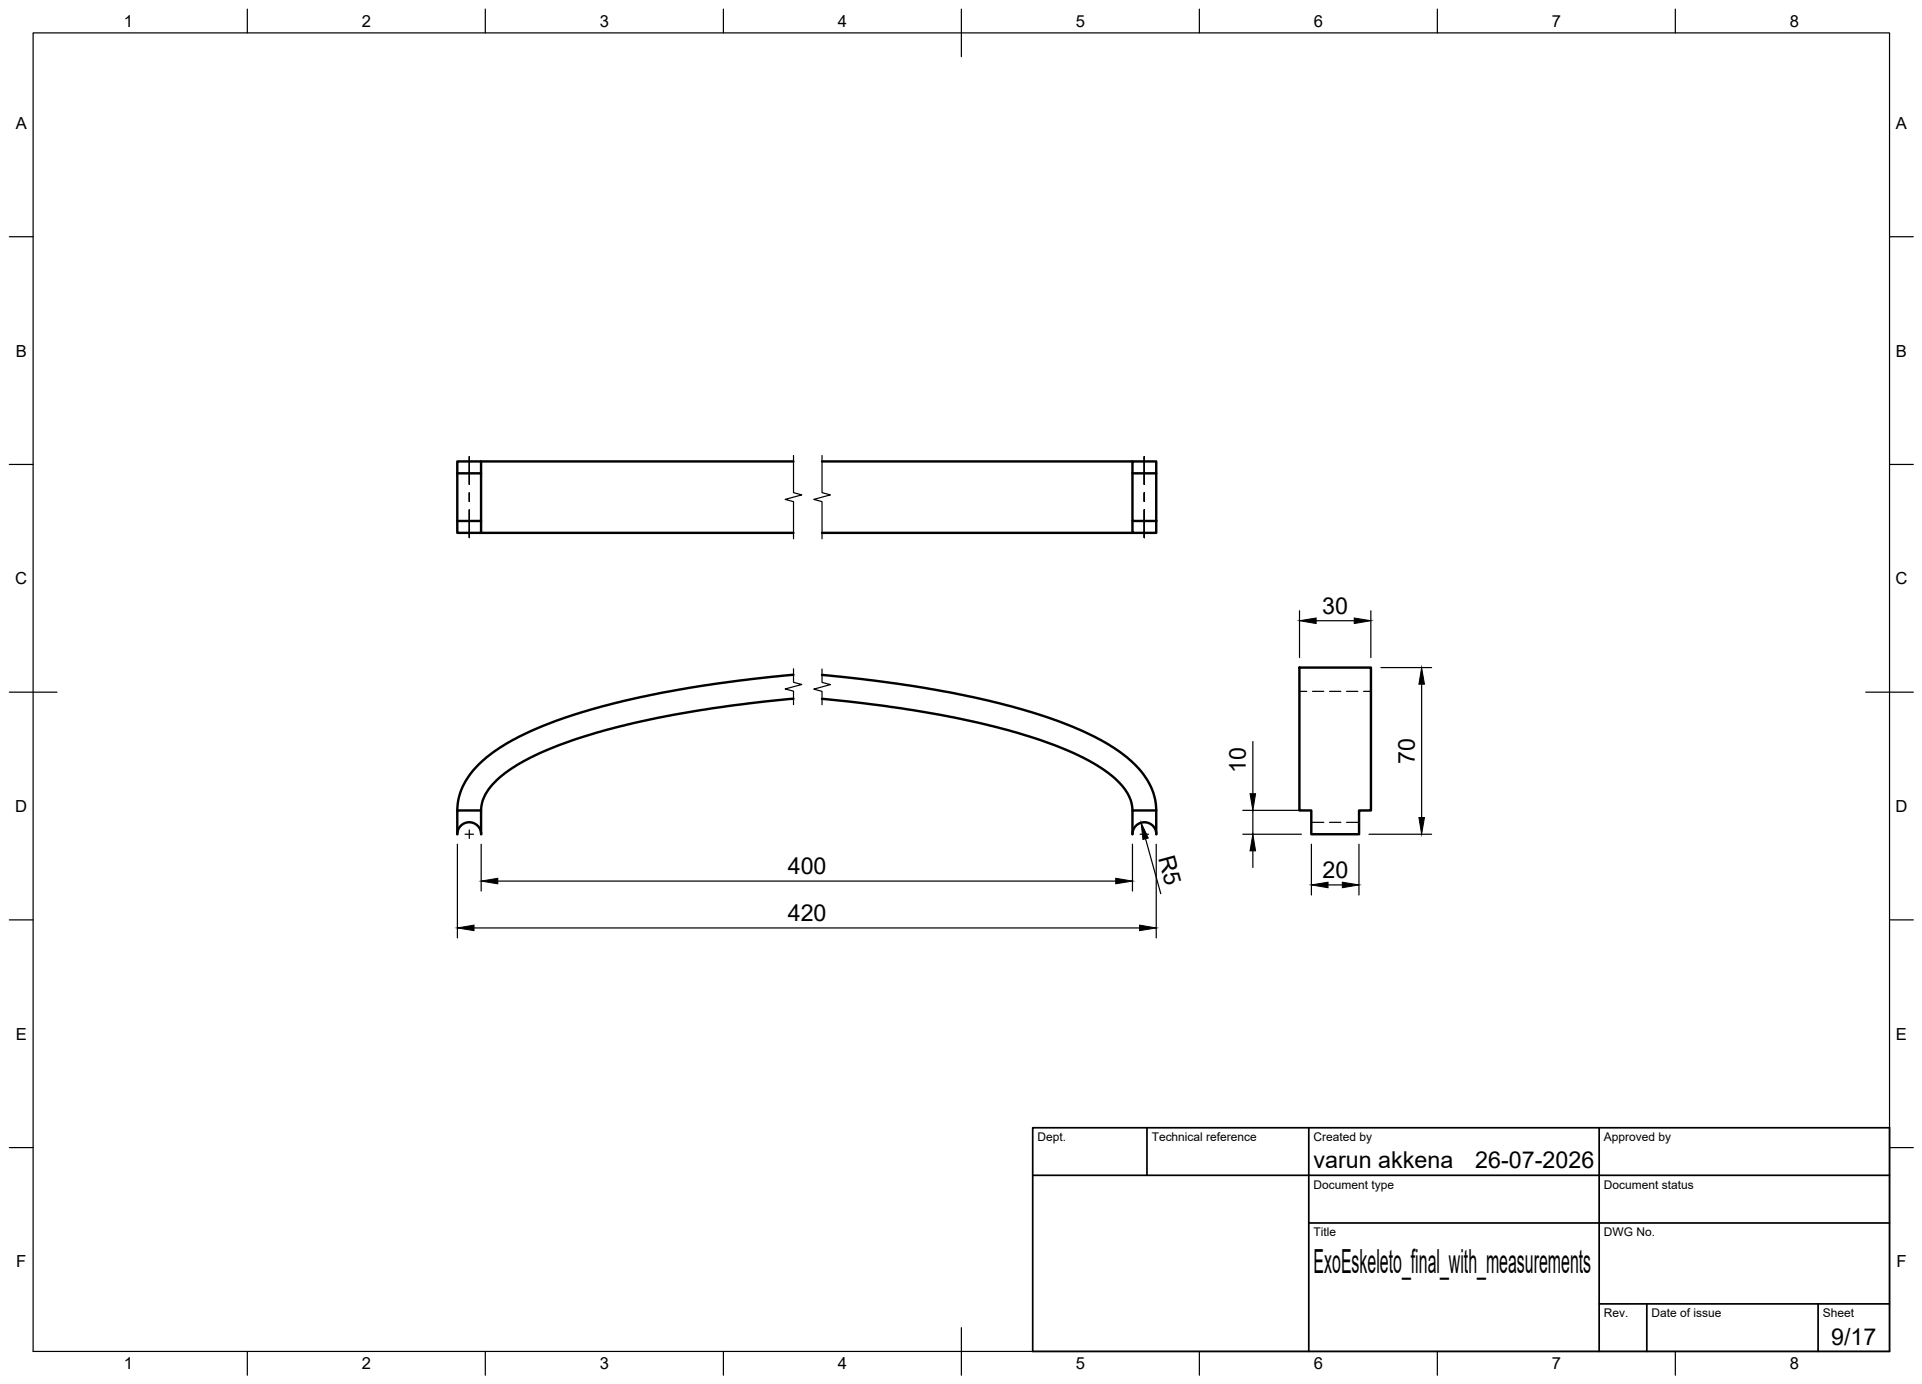
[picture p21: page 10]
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

A

A

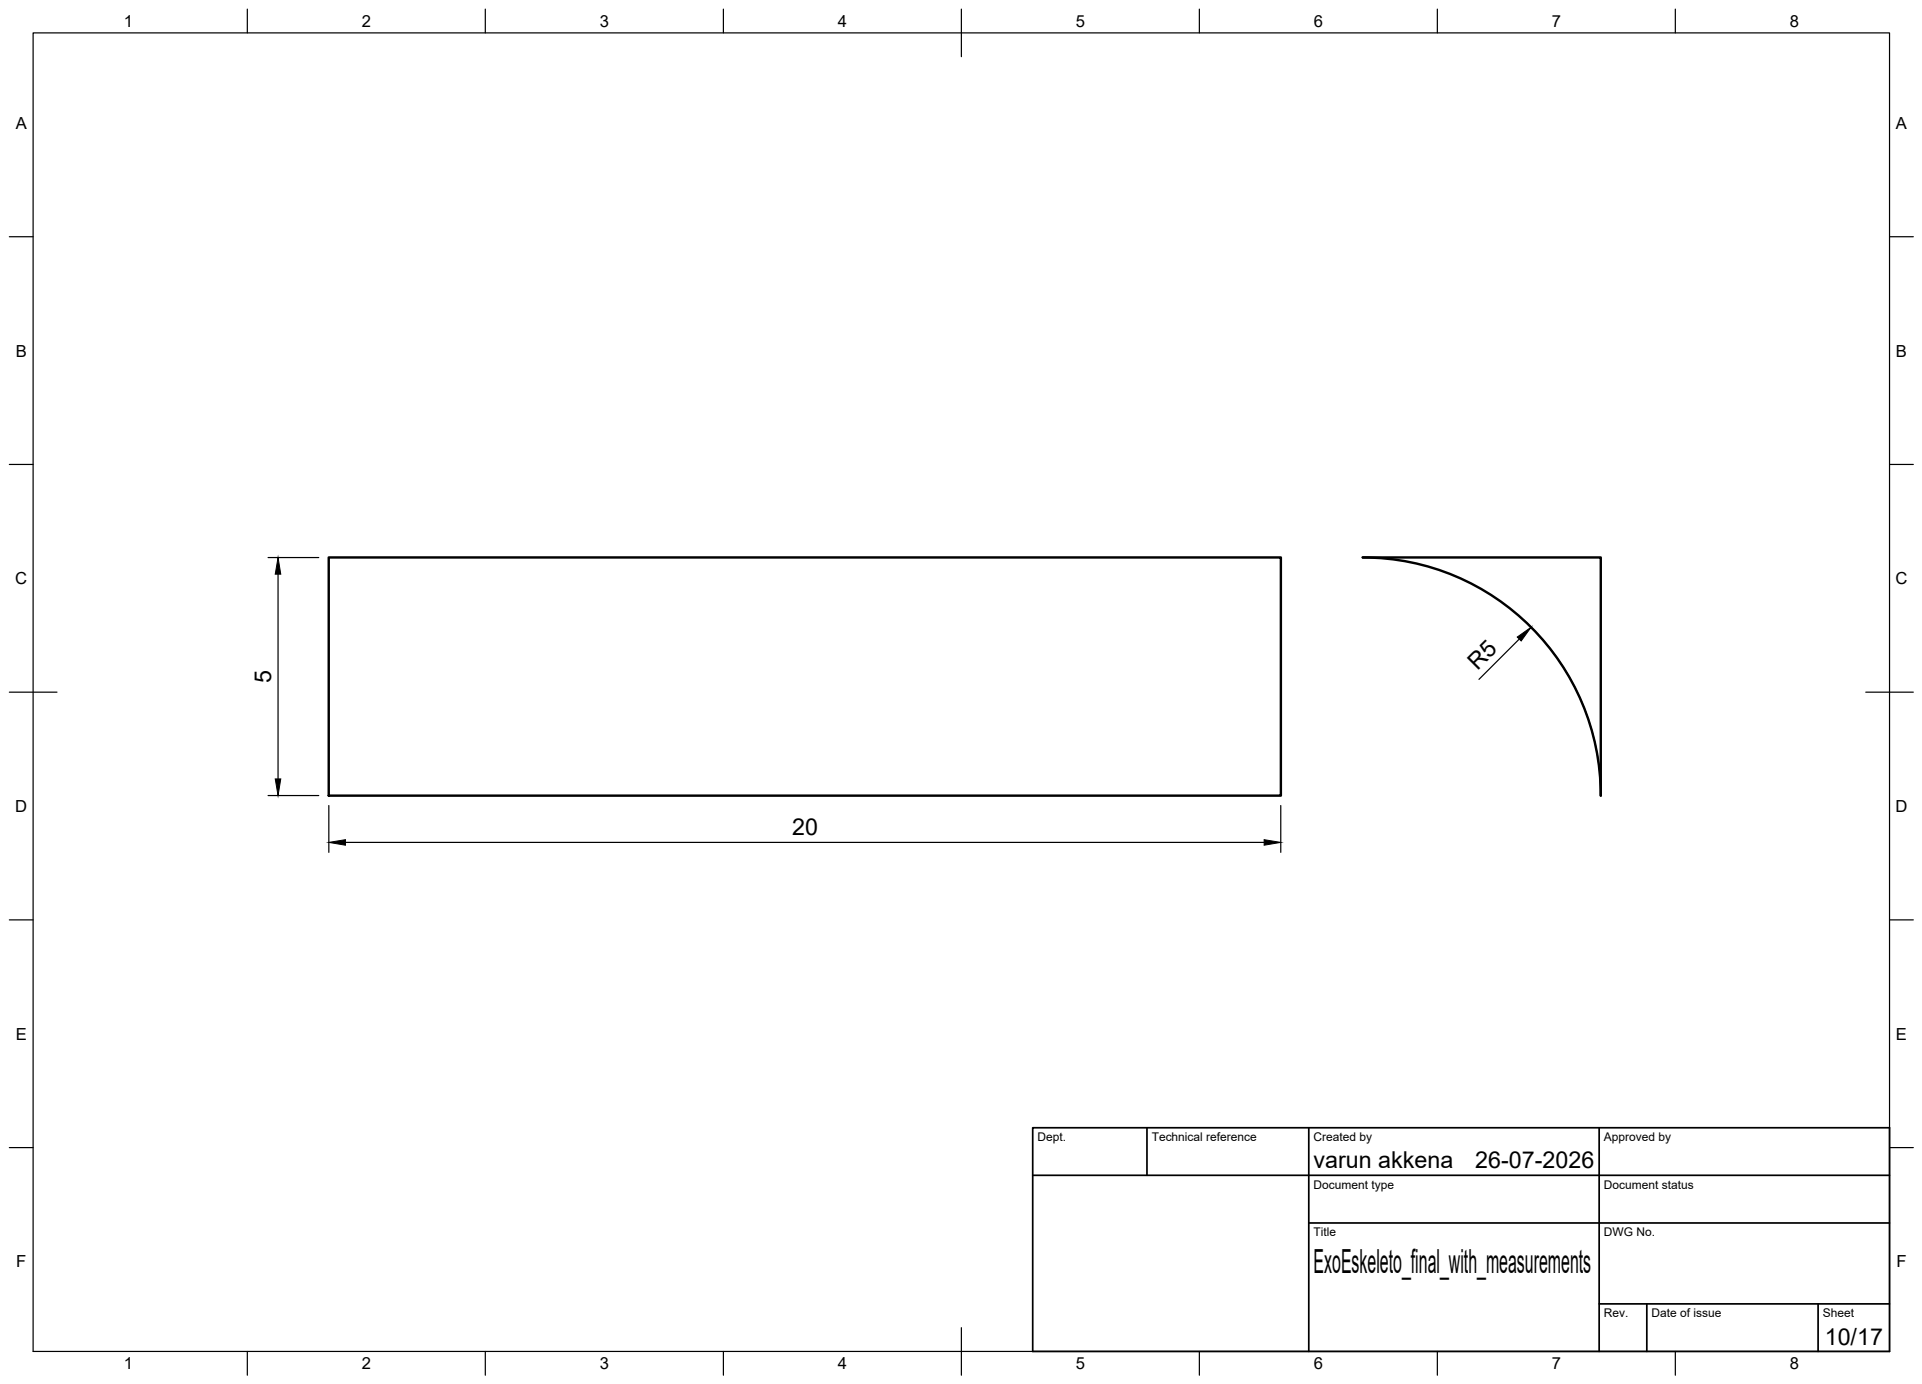
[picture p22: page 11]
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

A

A

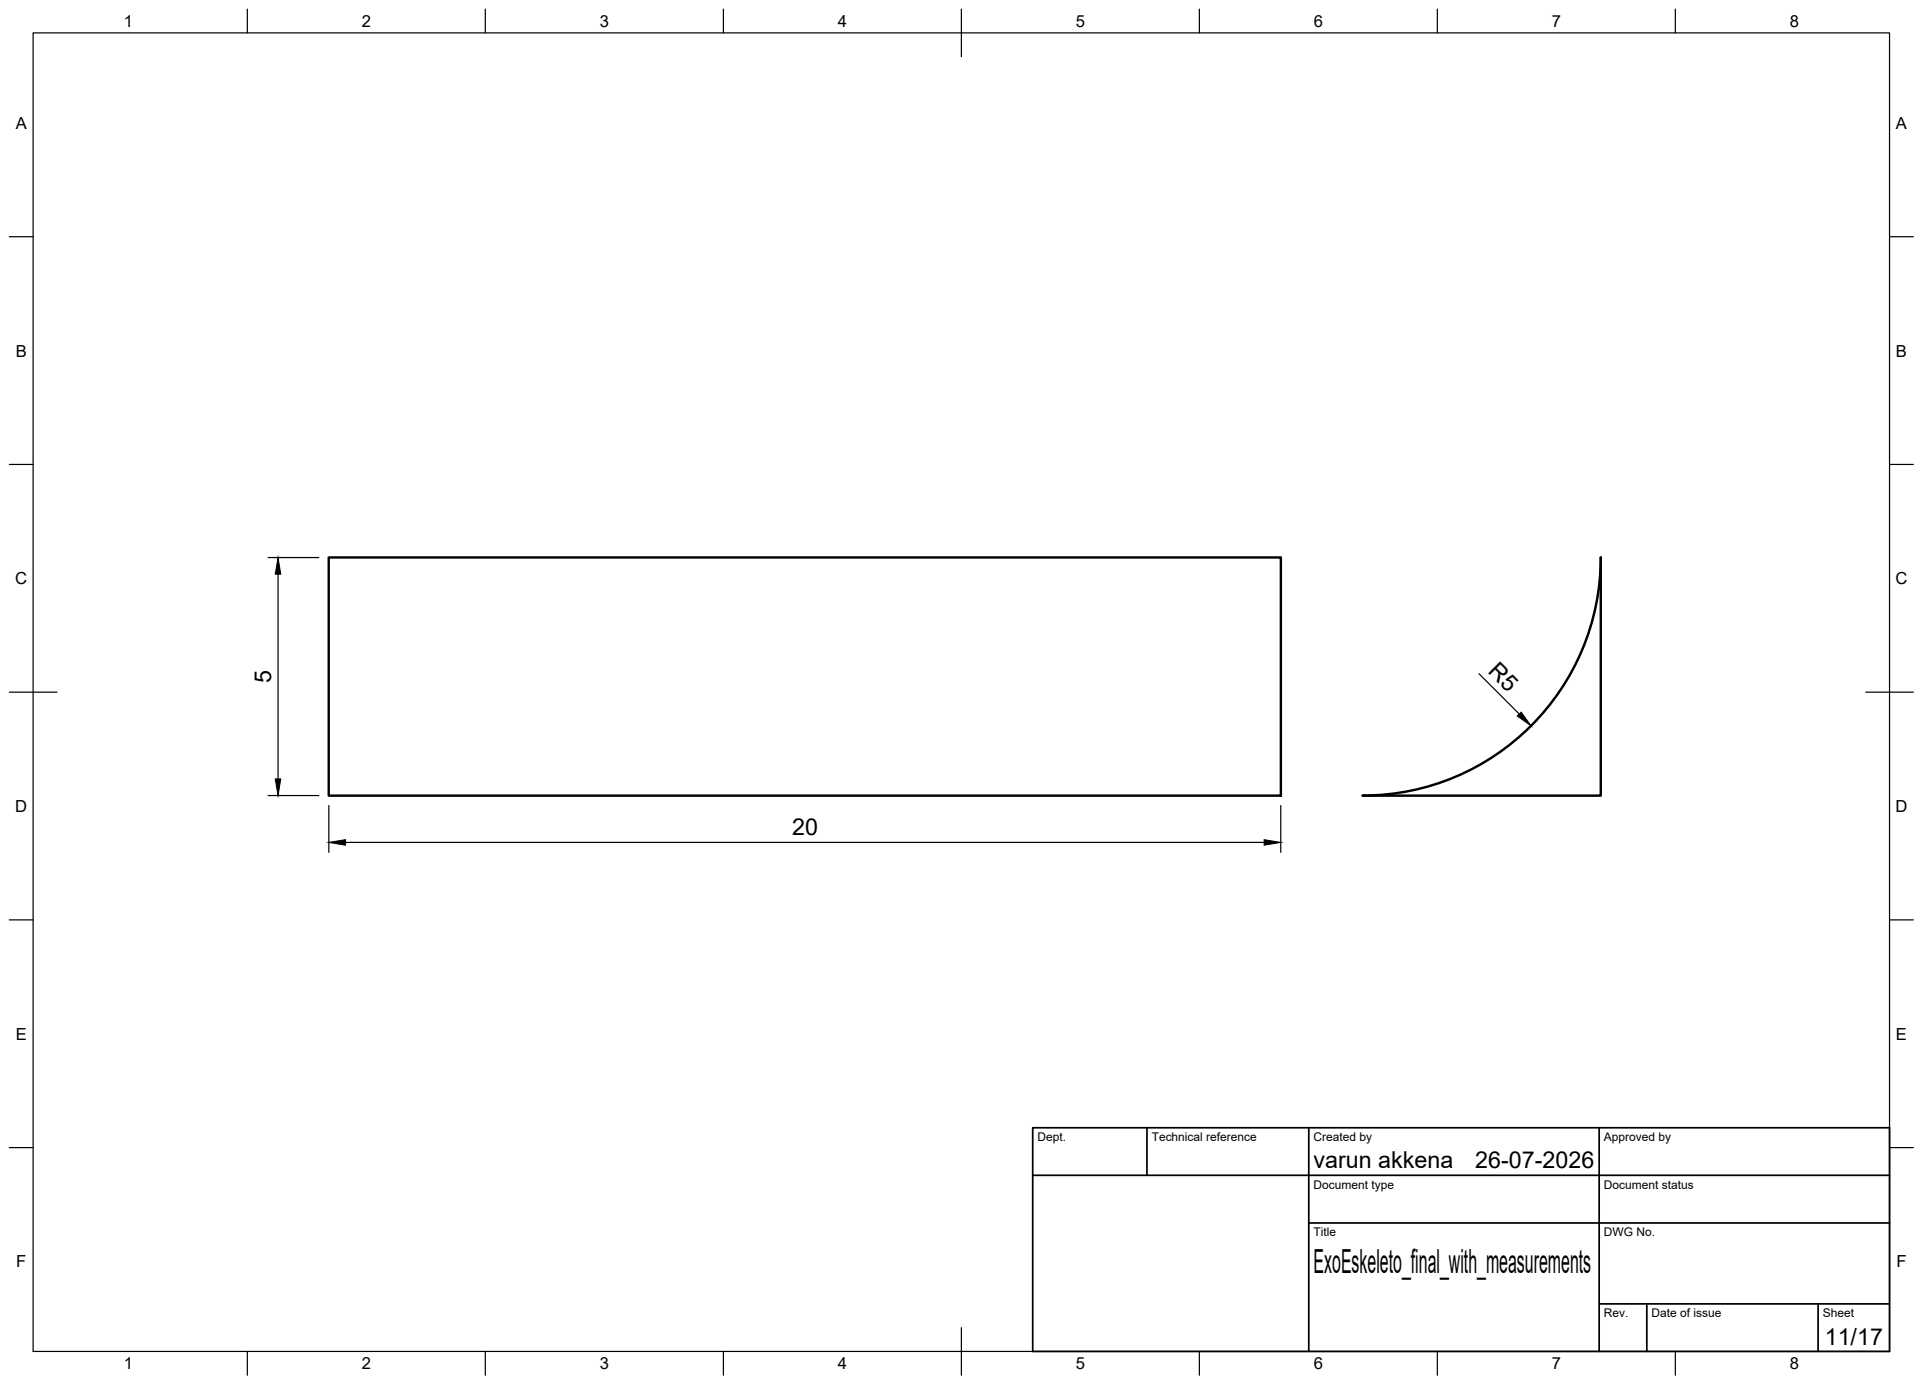
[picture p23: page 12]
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

A

A

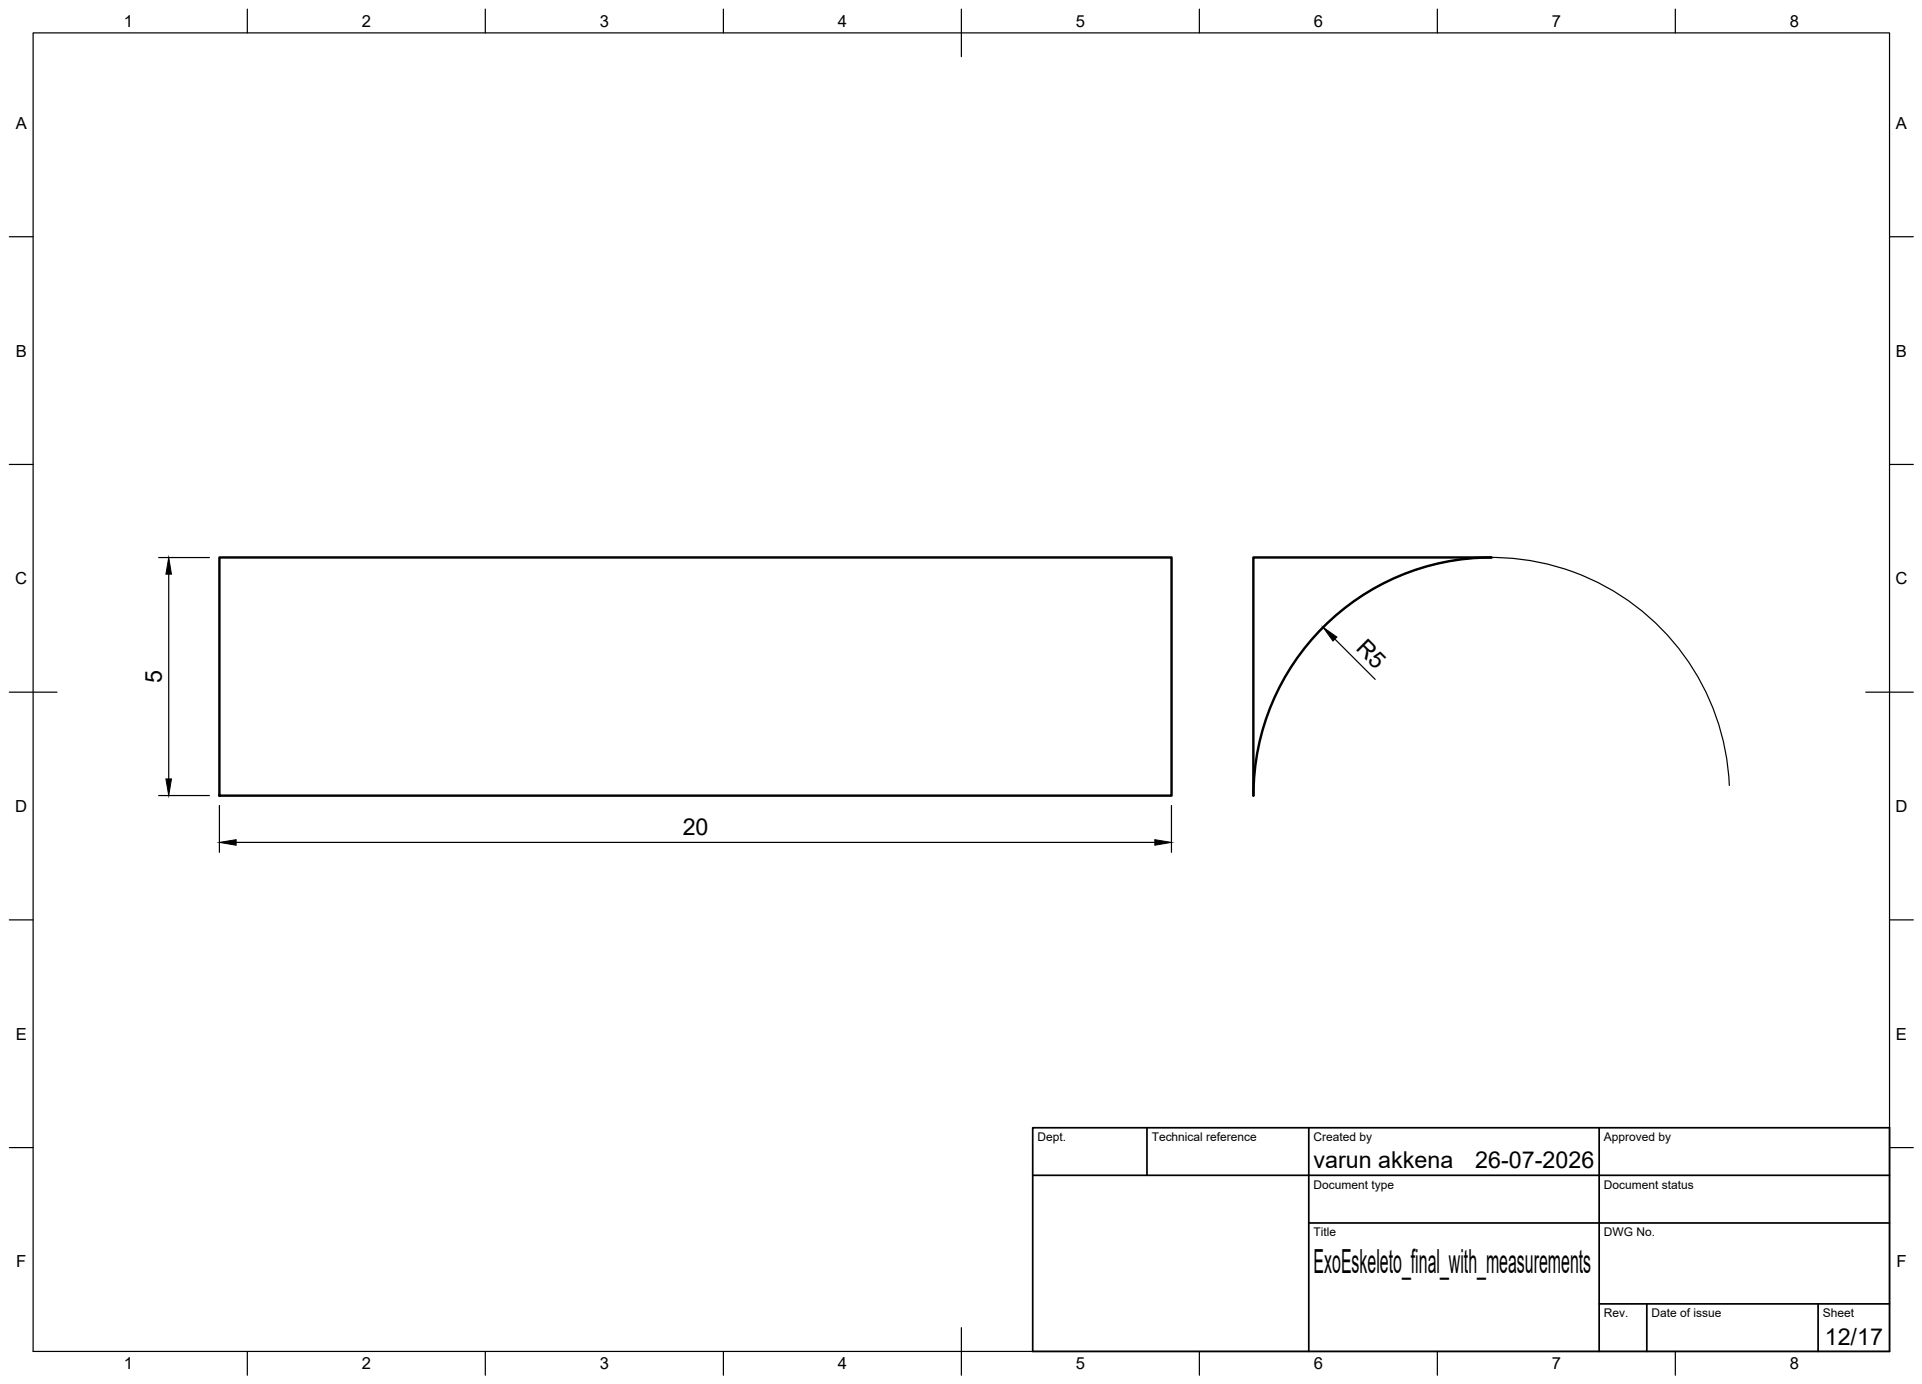
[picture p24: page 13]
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

A

A

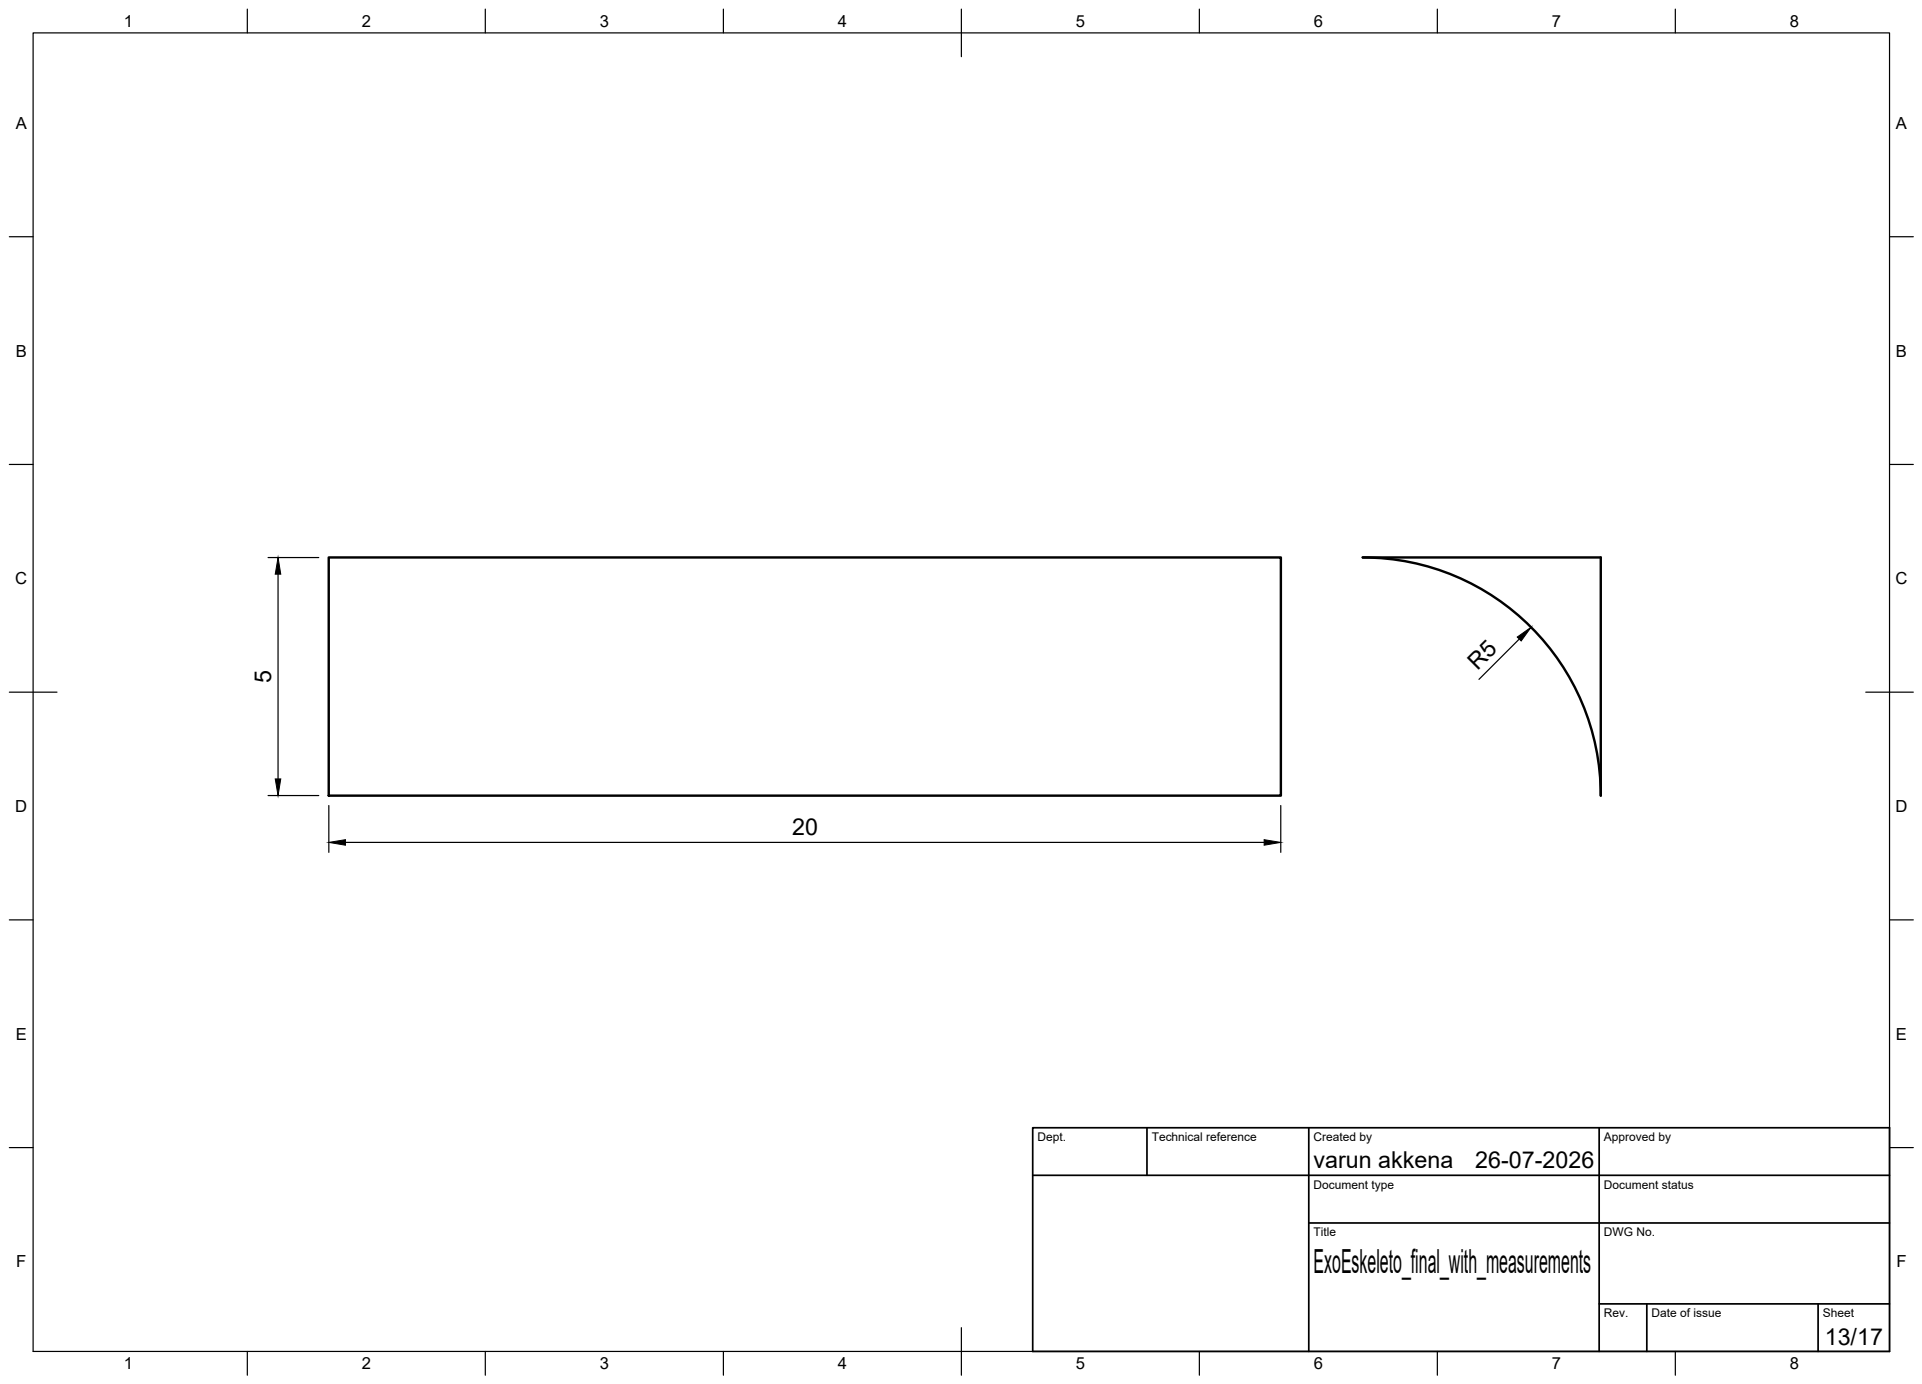
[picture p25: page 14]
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

A

A

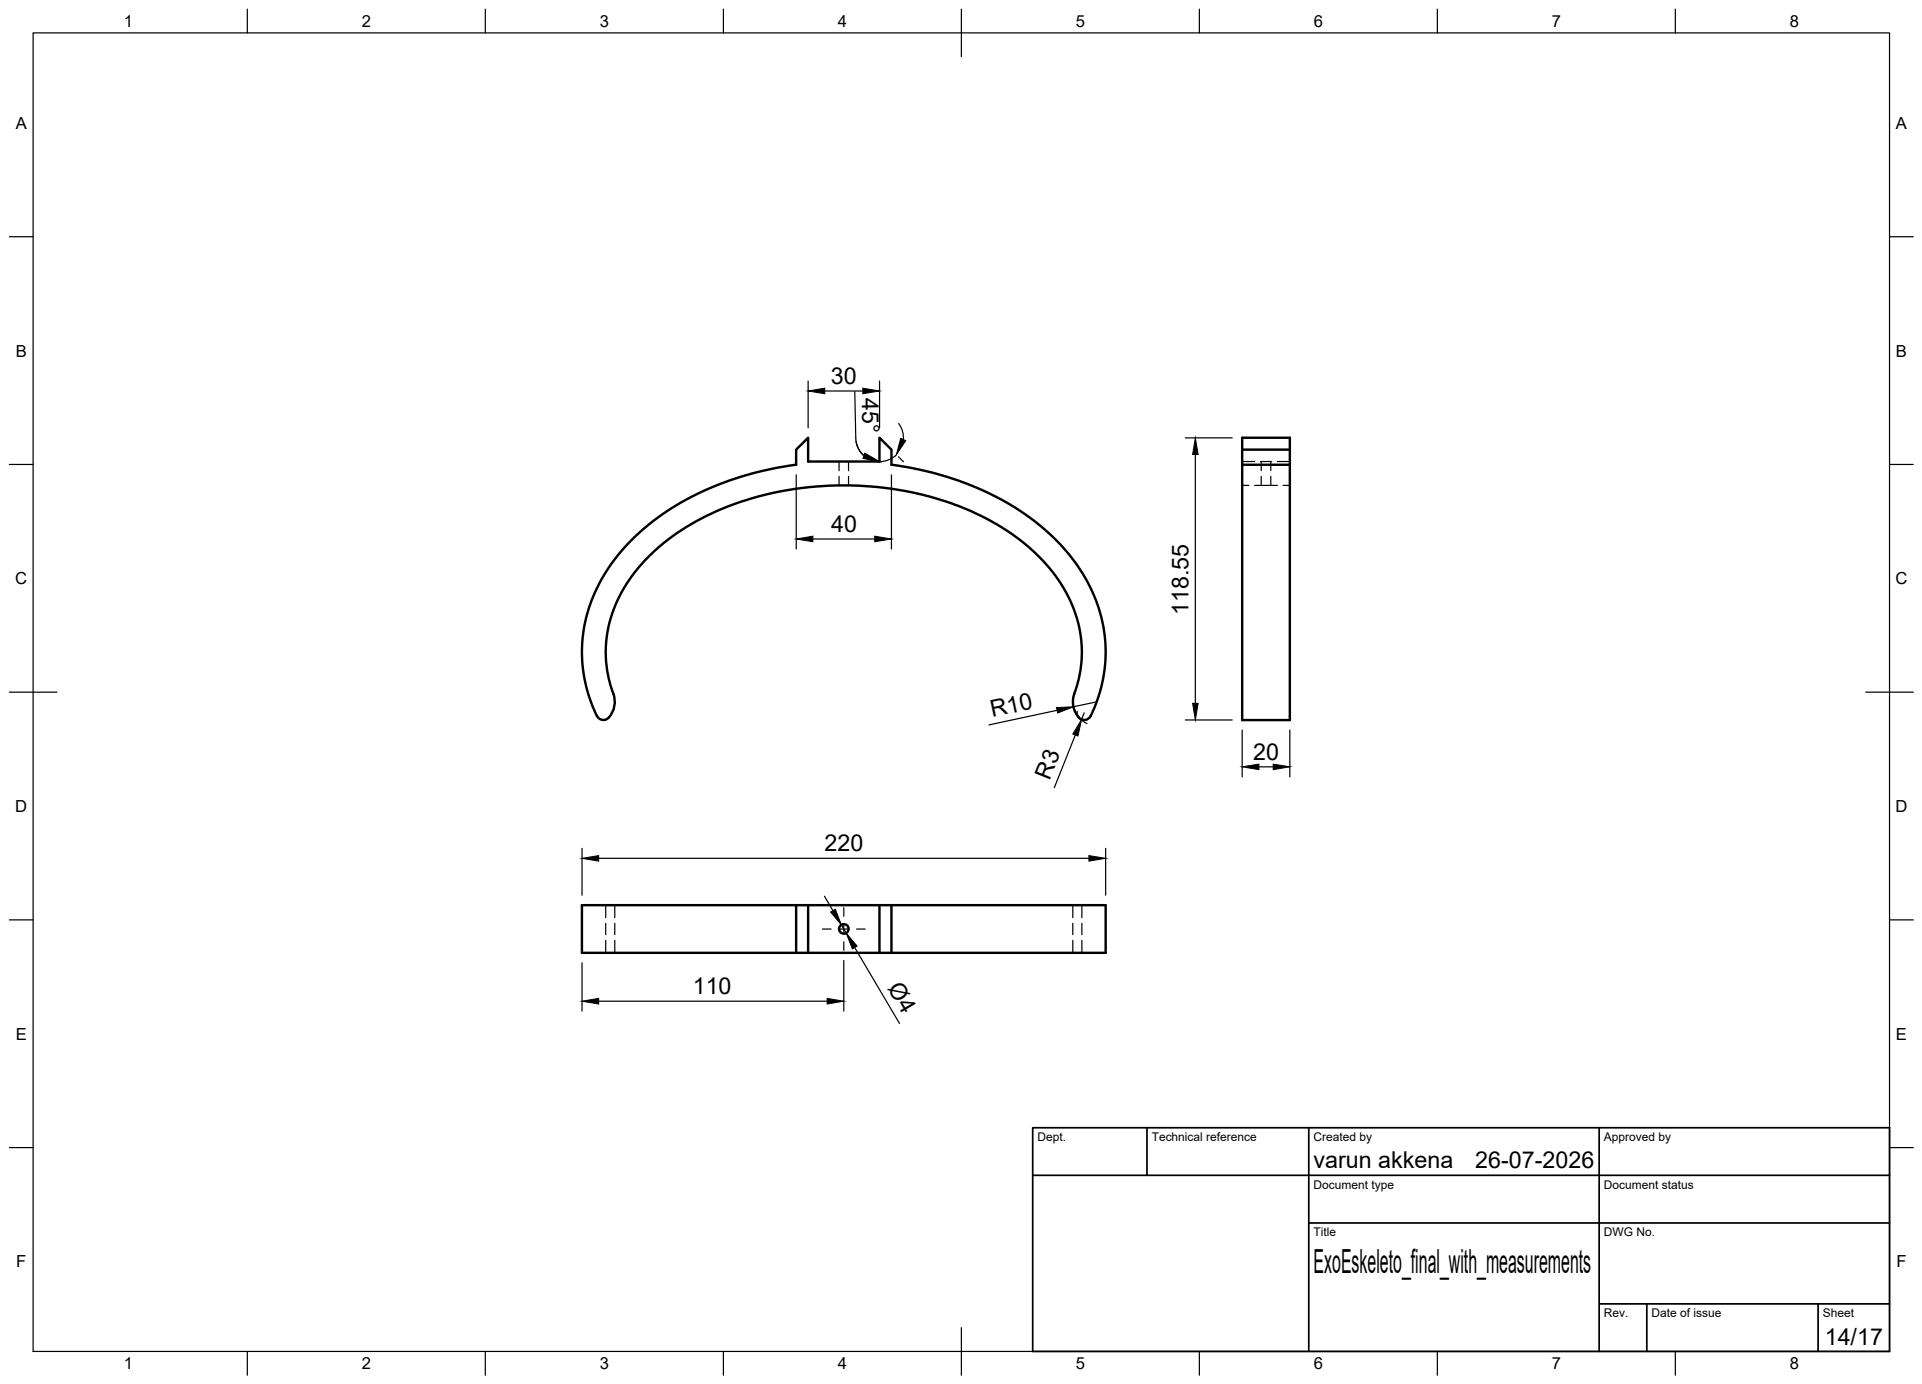
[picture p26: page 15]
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

A

A

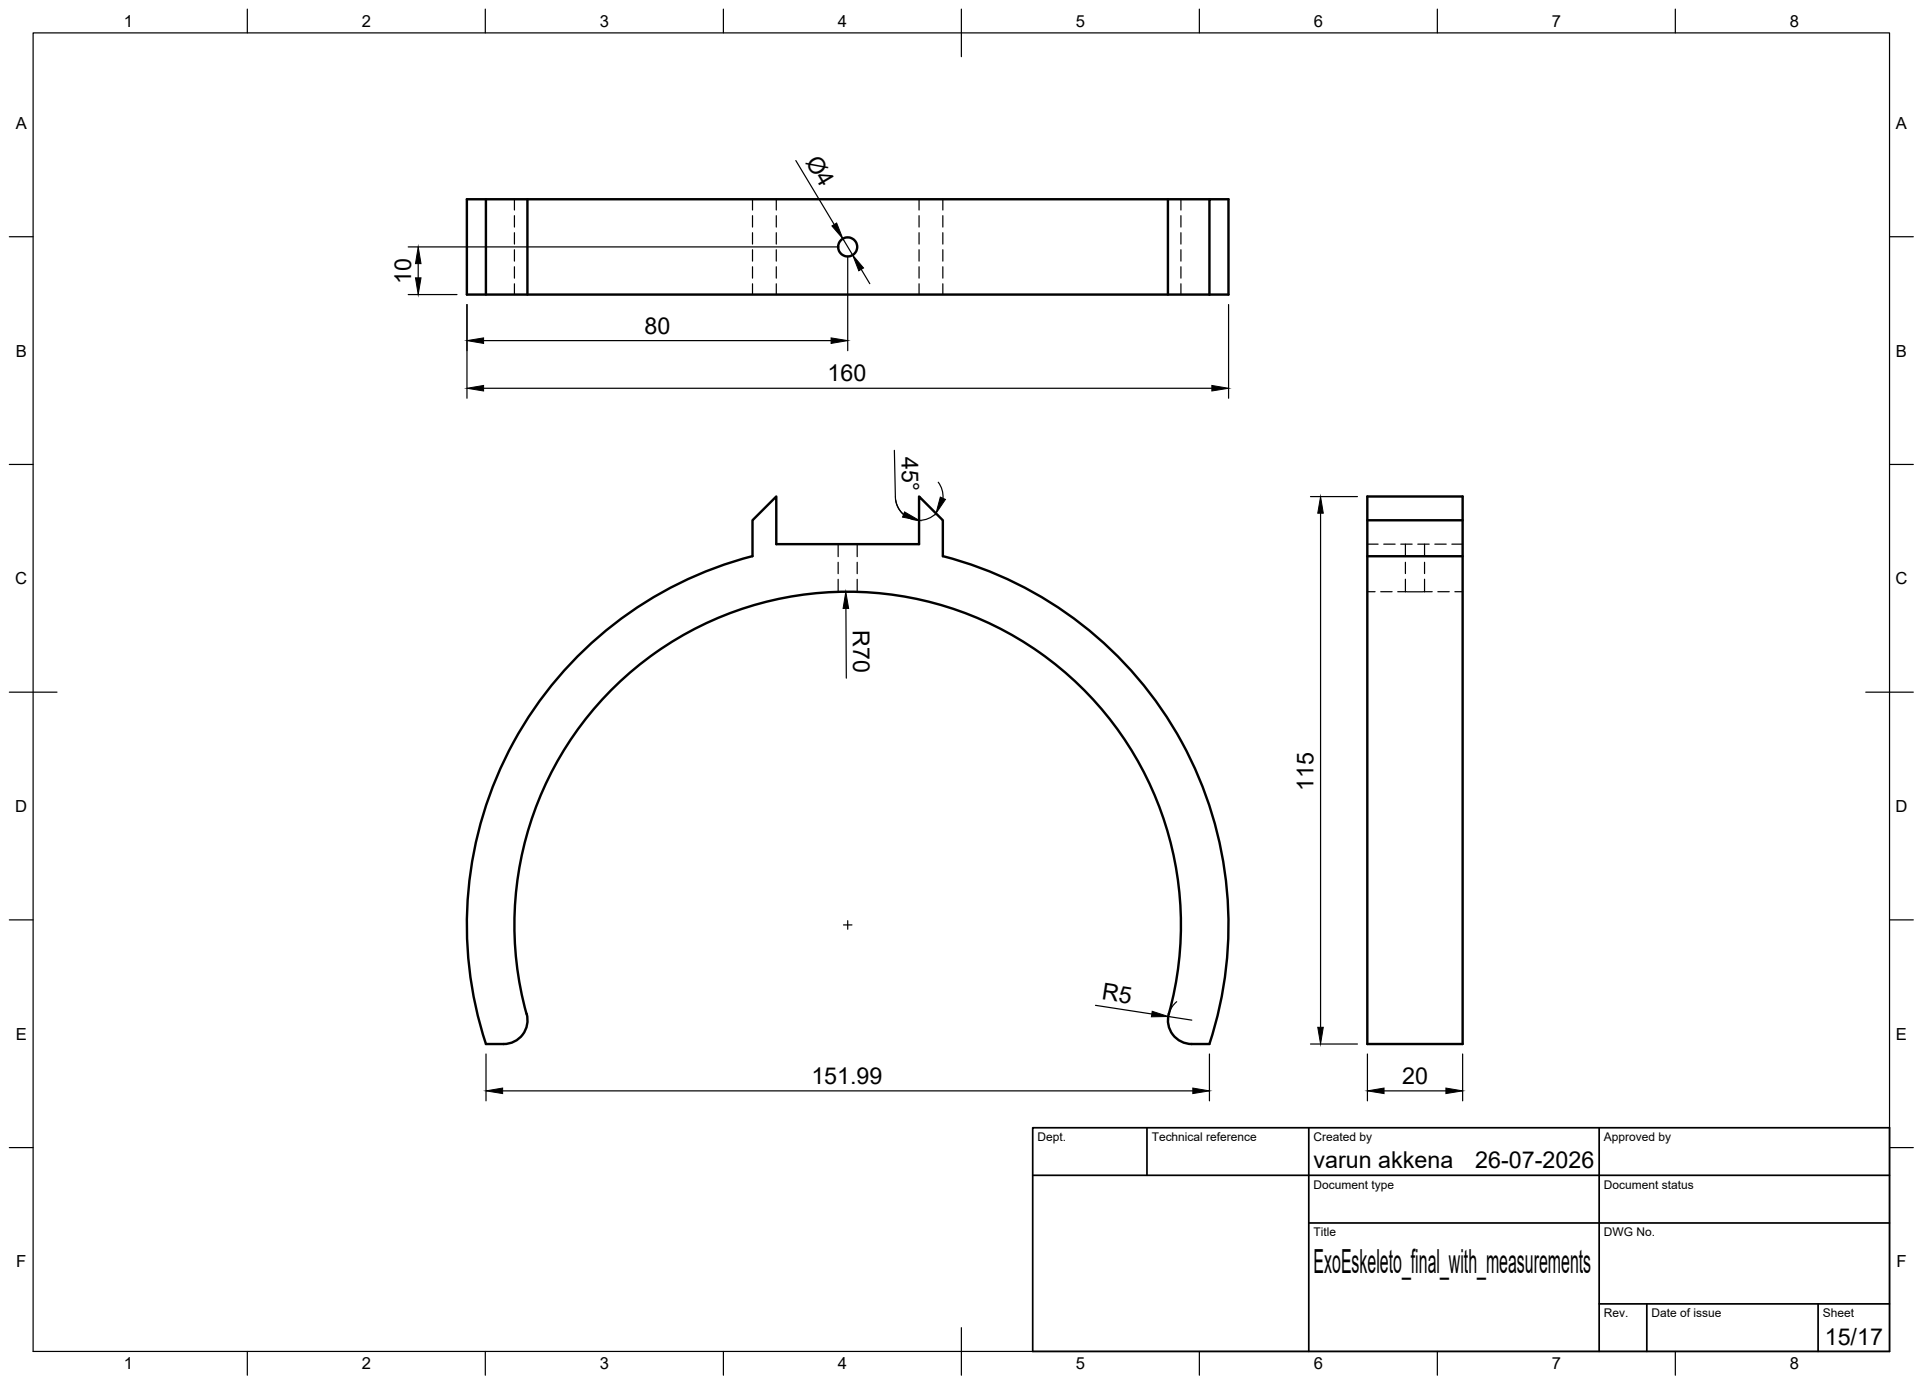
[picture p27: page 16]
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

A

A

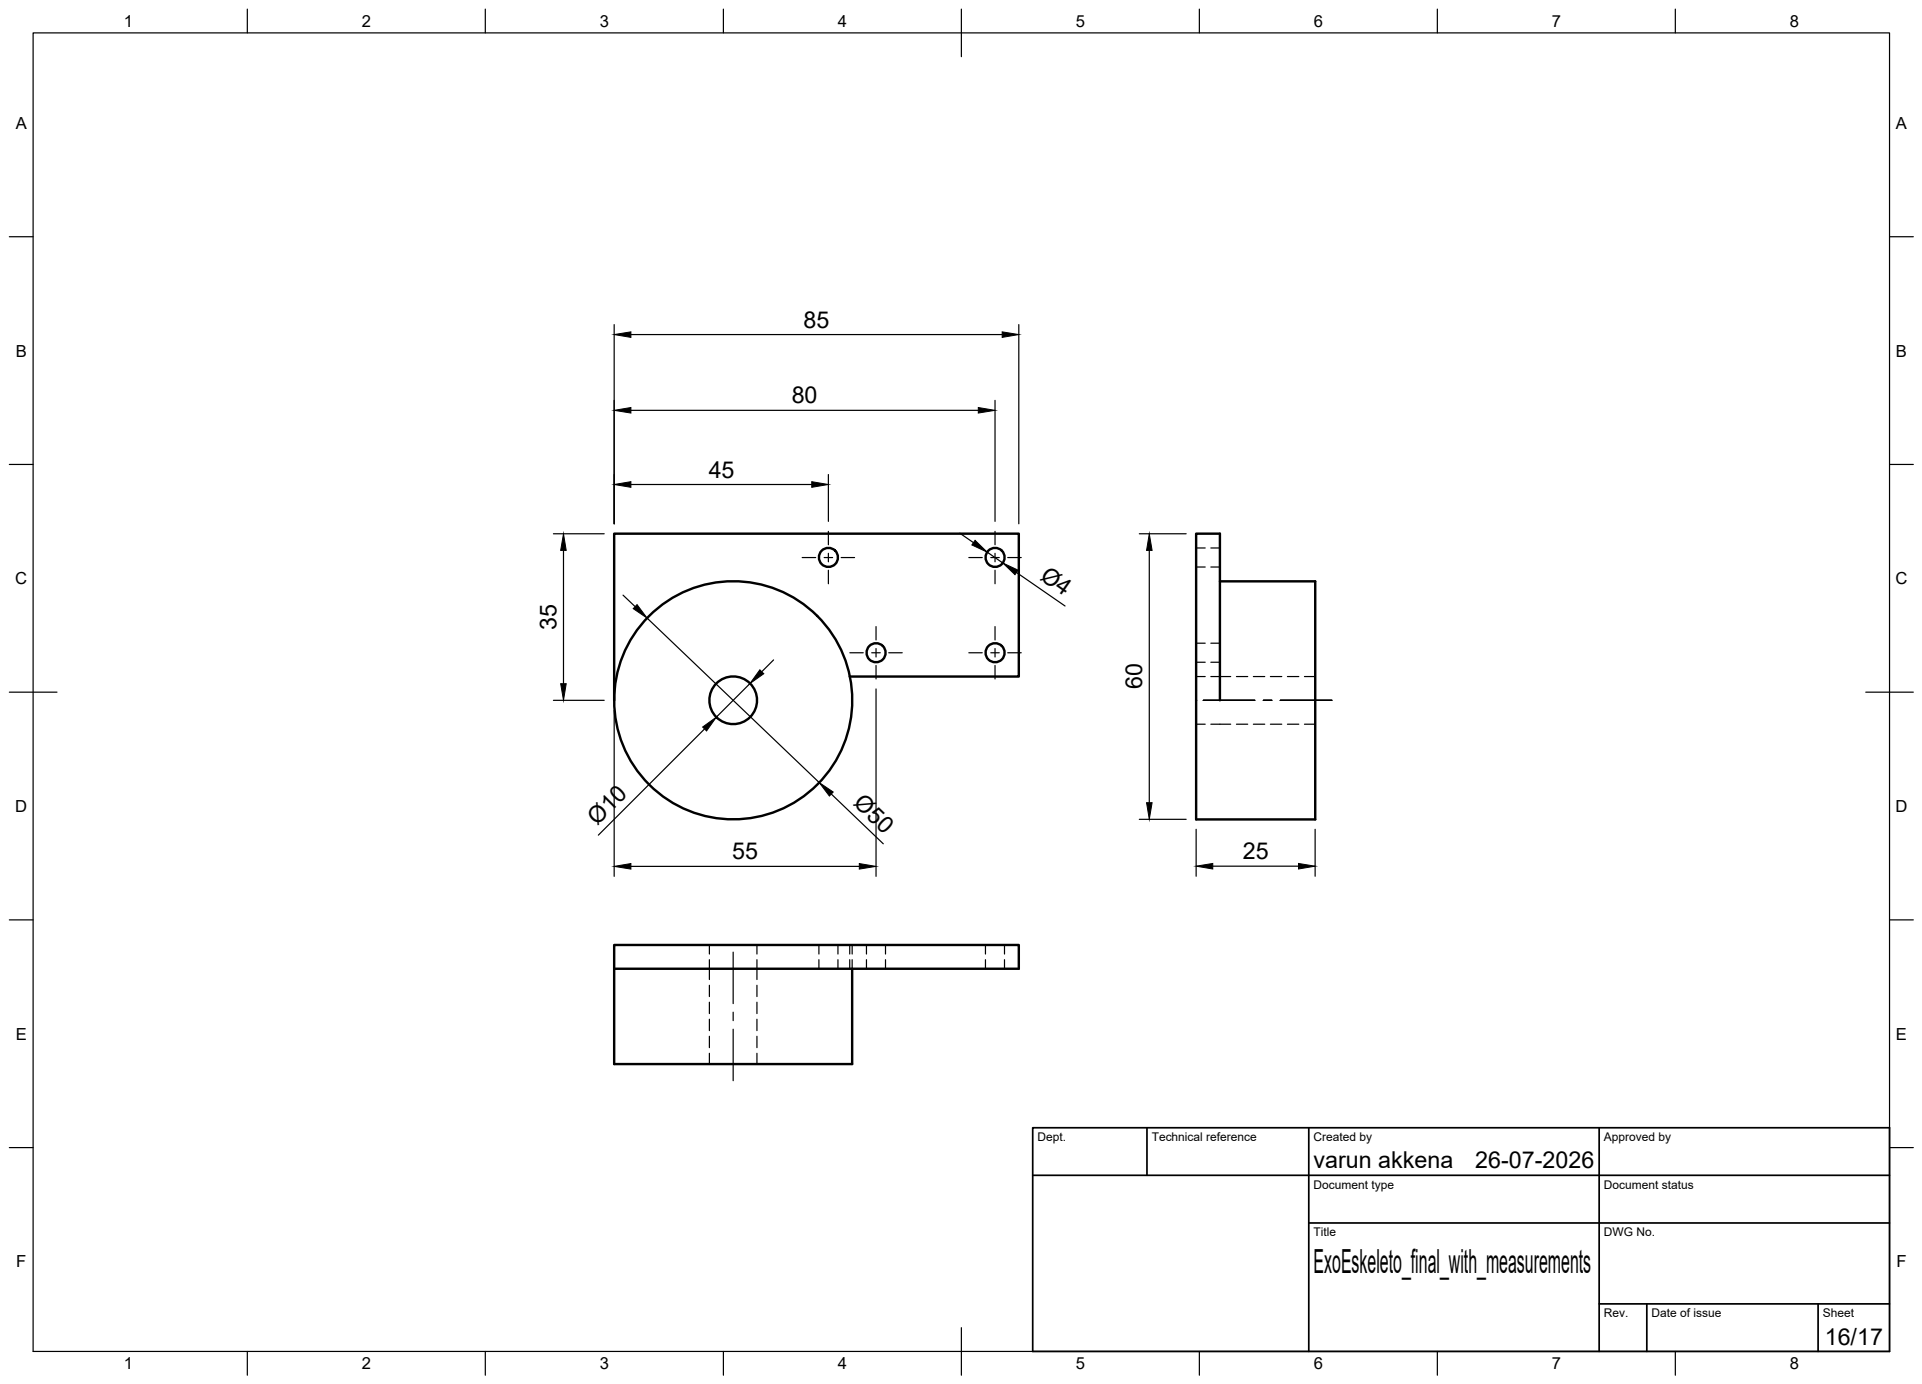
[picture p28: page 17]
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

A

A

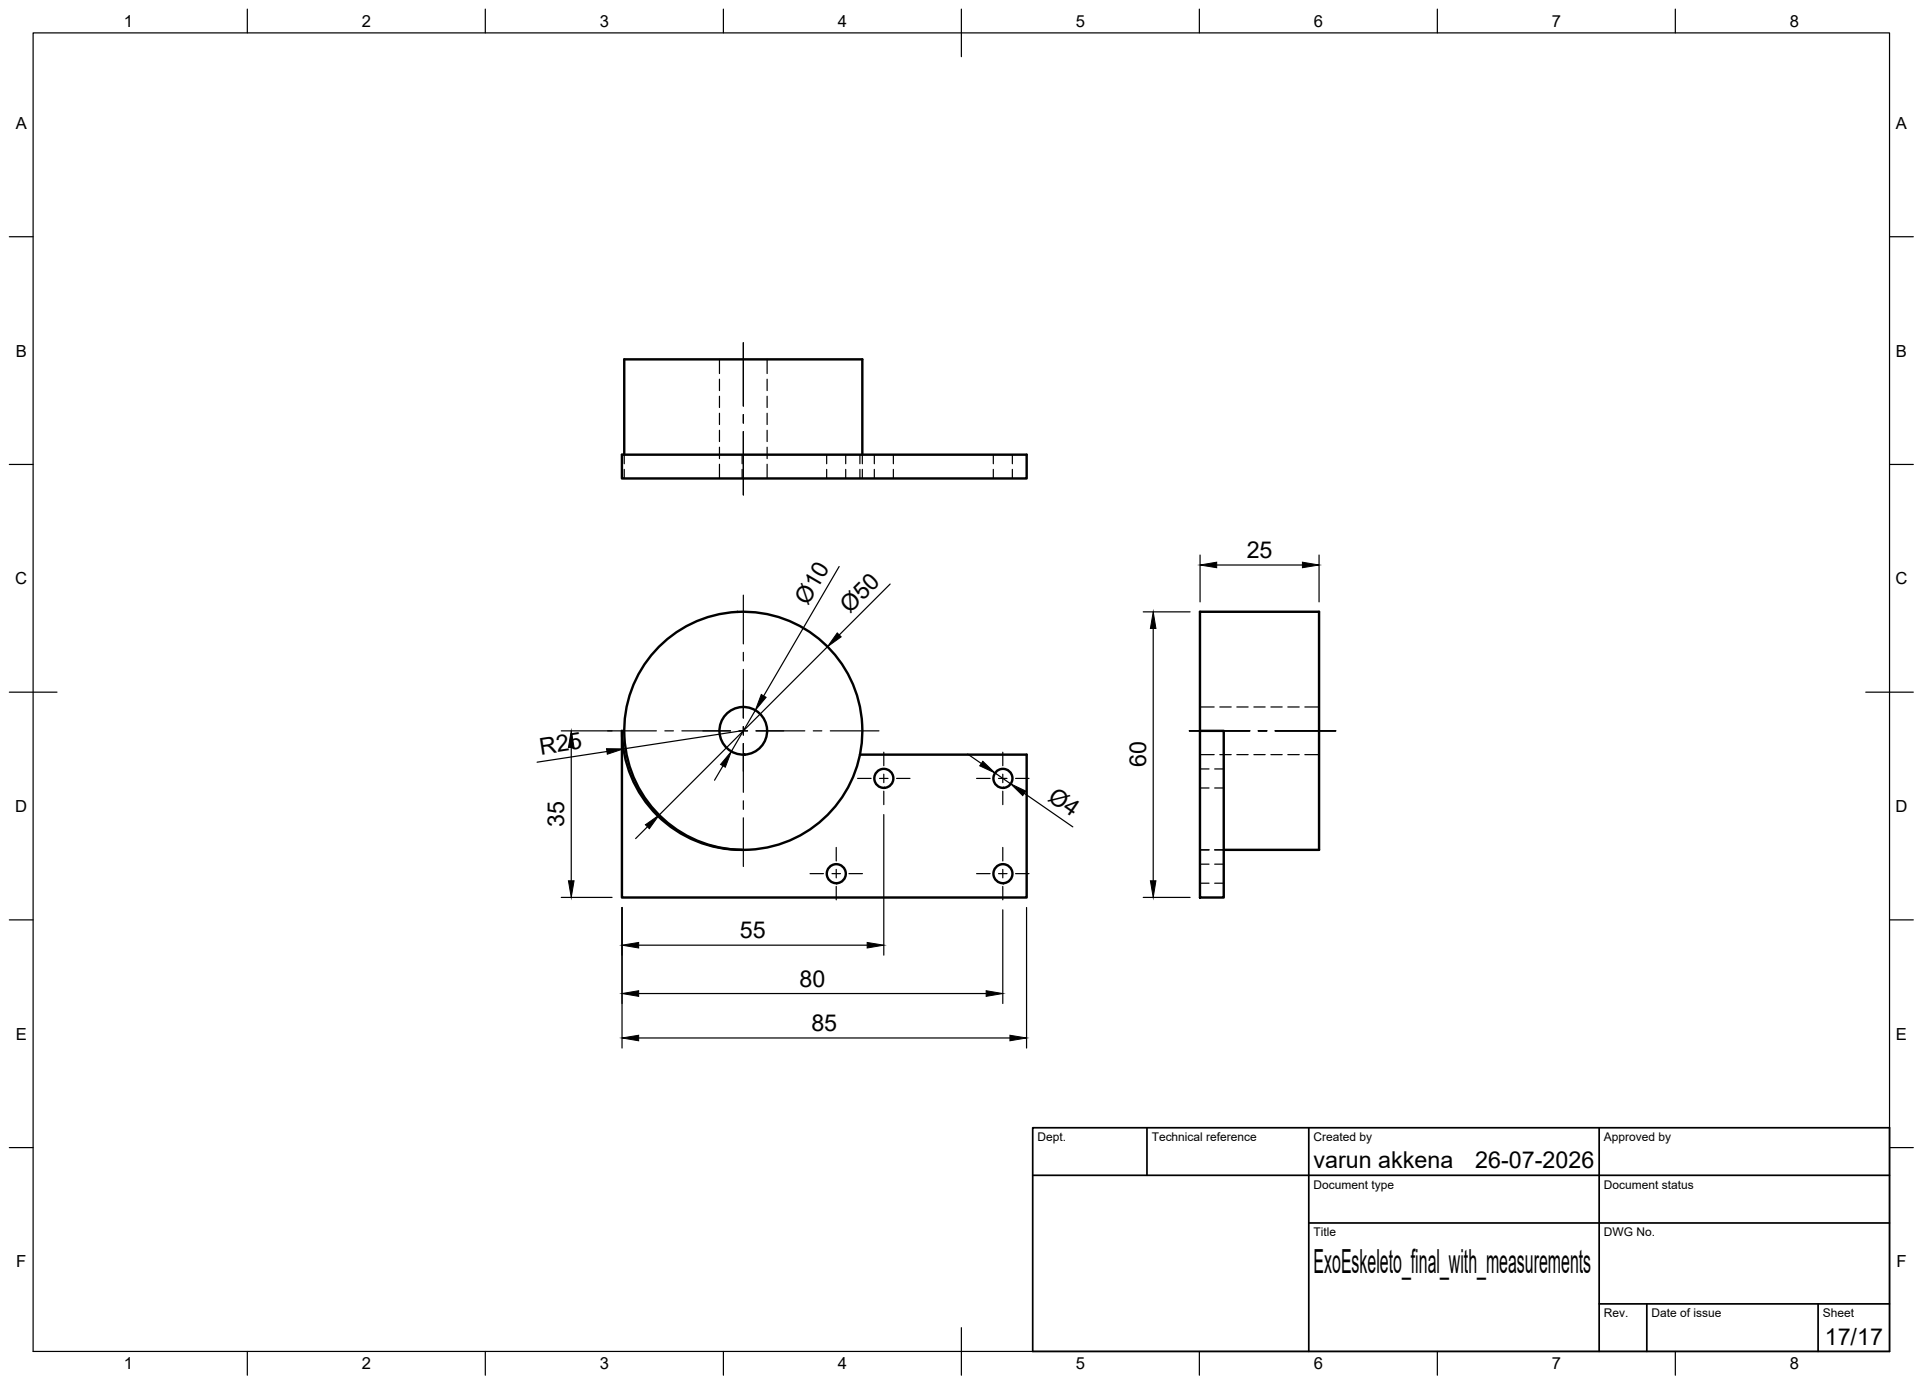
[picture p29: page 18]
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

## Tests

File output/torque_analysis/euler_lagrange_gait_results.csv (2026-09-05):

time_s | side | hip_angle_deg | knee_angle_deg | ankle_angle_deg | hip_speed_rad_s | knee_speed_rad_s | ankle_speed_rad_s | hip_accel_rad_s2 | knee_accel_rad_s2 | ankle_accel_rad_s2 | hip_reaction_nm | knee_motor_nm | ankle_motor_nm | hip_power_w | knee_power_w | ankle_power_w
0.000000 | left | -90.000000 | 0.000000 | 90.000000 | -1.568282 | -0.500426 | 0.630643 | -2.884258 | 8.172752 | 6.503739 | 3.387313 | 4.318929 | 3.480111 | -5.312260 | -2.161306 | 2.194709
0.040000 | left | -93.791700 | -0.679100 | 91.860600 | -1.635922 | -0.036923 | 0.960997 | -0.031646 | 8.568676 | 4.802099 | 9.444560 | 6.712514 | 3.407124 | -15.450561 | -0.247846 | 3.274235
0.080000 | left | -97.471500 | -0.307000 | 94.355700 | -1.526294 | 0.366300 | 1.154081 | 2.651916 | 6.909100 | 1.654250 | 12.428335 | 7.769696 | 3.065133 | -18.969296 | 2.846037 | 3.537413
0.120000 | left | -100.765900 | 0.909400 | 97.141800 | -1.300535 | 0.648345 | 1.156714 | 4.294733 | 3.814092 | -2.027859 | 10.772981 | 7.004402 | 2.592923 | -14.010636 | 4.541272 | 2.999269
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

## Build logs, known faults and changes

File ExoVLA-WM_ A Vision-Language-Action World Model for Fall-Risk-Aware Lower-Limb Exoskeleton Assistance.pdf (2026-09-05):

## Flagship Research Direction: A Vision-Language-ActionWorld Modelfor Fall-Risk-Aware Lower-Limb Exoskeleton Assistance

TL;DR

The strongest publishable opening is the first Vision-Language-Action (VLA) modelfor a

human-worn lower-limb exoskeleton: a VLM-backboned policy that fuses an

egocentric/torso camera + on-body proprioception + natural-language assistance/clinical

instructions and emits gait-phase-parameterized hip torque, with a learned latent world-

model head that predicts the wearer's future margin of stability (MoS) and a fall-risk scalar.

No published VLA targets worn assistive lower-limb devices — the entire VLA literature

(RT-2 2023, OpenVLA CoRL 2024, π0/π0.5, Octo, NVIDIA GR00T N1, Figure Helix) is

manipulation/humanoid — so the novelty lives exactly at the VLA × CV fusion the user

wants.

Concretely: QLoRA fine-tune a PaliGemma/π0-style 3B backbone with a flow-matching

action expert (single A100), and add a JEPA-/Dreamer-style latent predictor trained to

forecast extrapolated-center-of-mass (XCoM)/MoS and fall-risk from egocentric vision +

IMU. Language is necessary (clinician assist-as-needed intent, terrain/task priors, risk

posture), vision supplies anticipation, action is the torque profile — none alone suffices.

Headline result that would be CoRL/RSS/NeurIPS-competitive: on real hardware,

anticipatory vision+language assistance that (a) detects perturbations before the

wearer's physiological reactive response and reduces fall/stumble events under slip/trip

protocols, while (b) preserving metabolic benefit on par with Molinaro et al.'s unified

controller, and (c) generalizing zero-/few-shot to new terrains and stroke gait via language

conditioning without retraining the torque controller.

Key Findings (state of the art, 2023–2026)

1. VLA models are exclusively manipulation/humanoid; none control worn lower-limb

assistive devices. The flagship families — RT-2 (2023), OpenVLA (CoRL 2024; Kim et al., a 7B

model on Llama 2 with a fused DINOv2+SigLIP visual encoder trained on 970k real-world robot

demonstrations, beating RT-2-X 55B by 16.5% absolute success across 29 manipulation tasks),

Octo, π0 and π0.5 (flow-matching VLAs on a PaliGemma 3B backbone + ~300M action expert),

NVIDIA GR00T N1 (humanoid), Figure Helix, Gemini Robotics — all address manipulation or

generalist/humanoid robots. "HumanoidExo" and ExoArm-style devices use exoskeletons only

as teleoperation data-collection rigs for humanoid manipulation, not as the controlled assistive

device. The only language→lower-limb-exo work is speech-command finite-state-machine

planning (Guo et al., ICHMS 2024) and upper-limb semantic-intent assistance

(arXiv:2508.10378) — neither is a vision-language-action policy. This is a genuine open gap and

the core novelty lever. (Caveat: confirm against the very newest 2026 preprints before claiming

primacy.)

2. CV-for-exoskeletons exists but is narrow and not fused with language or action foundation

models. Terrain classification (Laschowski et al., EMBC 2021; gimbal-stabilized MobileNetV2

systems), Exosense vision-centric scene understanding (arXiv:2403.14320), environment-based

assistance modulation for a hip exosuit (arXiv:2211.15346), and egocentric optical-flow

kinematics prediction (Nature Sci. Data 2023). The anchor group's own CV work (Song, Ivanyuk-

Skulskyi, Krieger, Luo, Kang, ICORR 2025) uses human pose estimation to personalize an IMU-

based temporal convolutional network (TCN) from only 1–2 gait cycles, reducing kinematics

RMSE by 9.7% and 19.9% on stiff-knee gait. All of this is single-modality perception feeding a

classifier or estimator — not a unified VLA, and not closed-loop torque.

3. The anchor group has built every component except the fusion.

Unified joint-moment control (Molinaro, Kang, Young, Science Robotics 9(88):eadi8852, 20

Mar 2024): a TCN that "achieved an average root mean square error of 0.142 newton-meters

per kilogram across 35 ambulatory conditions without any user-specific calibration" (R² =

0.840 ± 0.045). It reduced metabolic cost during level-ground walking by 5.4 ± 5.6% vs. No

Exo and 12.7 ± 2.8% vs. Zero Torque, and during 5° incline ascent by 10.3 ± 4.4% vs. No

Exo and 17.8 ± 5.1% vs. Zero Torque; hip-joint positive work fell 29.2 ± 10.9% (level

ground).

Rapid slip detection (Peterson, Leestma, Kang, Young, IEEE T-MRB 2025): XGBoost on

native hip-exo sensors, 155.06 ms detection at 96.25% accuracy for early-stance slips

(user-independent).

Kinematic perturbation detection (Tagliaferri, Campeggi, Beck, Kang, ICORR 2025): nine-

subject cross-validation gives 95.5% accuracy with a 33.1% gait-cycle delay,

outperforming the whole-body-angular-momentum benchmark (cite the published

95.5%/33.1%, not the 98.8%/23.1% pilot).

Stroke personalization (Kang et al., IEEE T-RO 2025): online adaptation improved gait-

phase estimation by 40.9% (able-bodied) and 65.9% (stroke) and cut torque error 32.7%

with <1 min of adaptation; also demonstrated cross-hardware transfer to a commercial

device.

Physics-informed / neuromusculoskeletal sim policies (Park, Song, Kang, arXiv:2603.04166,

2026 — RL teacher with muscle-synergy prior, sim-to-real r = 0.82 ± 0.19, RMSE 0.03 ± 0.01

Nm/kg; Chiu et al., ICORR 2025 — adversarial imitation, 5.24° RMSE).

Conceptual anchor (Kang, Mitra, Seethapathi, bioRxiv 2026): humans navigate an

"environment-dependent risk landscape by mitigating the statistical probability of falling,"

explained by a global probabilistic fall risk rather than local step instability — directly

motivating a fall-risk objective for control.

4. World models are mature for legged/humanoid locomotion but unused for human-worn

assistance. DreamerV3 (RSSM latent imagination; Hafner et al., Nature 2025), Denoising World

Model Learning (RSS 2025 humanoid terrain locomotion), and V-JEPA 2 / V-JEPA 2-AC (Meta,

arXiv:2506.09985, released 11 Jun 2025): pretrained on "over 1 million hours of internet-scale

video," with a 300M action-conditioned predictor fine-tuned on "less than 62 hours of unlabeled

robot videos from the Droid dataset," deployed "zero-shot on Franka arms in two different labs."

These predict robot dynamics — none predict human biomechanical stability states for an

assistive device.

5. Balance biomechanics give a principled, quantitative target. MoS is the signed distance

from the XCoM to the base-of-support boundary; per Hof, Gazendam & Sinke (J. Biomechanics

38:1–8, 2005), "the 'margin of stability' b, the minimum distance from XcoM to the boundaries of

the BoS." Beck, Shepherd, Rastogi, Martino, Ting & Sawicki (Science Robotics 8(75):eadf1080, 15

Feb 2023) showed "wearable exoskeletons have the potential to enhance user balance after a

disturbance by reacting faster than physiologically possible," with anticipatory ankle torque

improving standing balance by 9% — the strongest motivation for an anticipatory, vision-

conditioned predictive controller. For metabolic calibration, Slade, Kochenderfer, Delp & Collins

(Nature 610:277–282, 2022) reported real-world personalized assistance "reduced metabolic

energy consumption by 23 ± 8% when participants walked on a treadmill at a standard speed of

1.5 m s⁻¹."

Details

Flagship idea: "ExoVLA-WM" — a language-conditioned, vision-grounded,fall-risk-

predictive assistance policy

(a) Problem statement & gap. Current lower-limb exoskeleton controllers are reactive and

proprioception-only: they estimate biological joint moments or gait phase from on-body

IMUs/encoders and apply assistance, but they (i) cannot anticipate terrain or perturbations

beyond the body's own sensed deviation, (ii) cannot be re-tasked by natural language, and (iii)

optimize metabolic cost or moment-tracking without an explicit, predictive model of fall risk. We

propose a single VLA policy that ingests an egocentric/torso RGB(-D) camera, on-body

proprioception (IMU + exo encoders), and a natural-language instruction, and outputs gait-

phase-parameterized hip assistance torque — while a coupled latent world-model head predicts

the future XCoM/MoS trajectory and a scalar fall-risk probability that gates assistance

aggressiveness. The gap filled: vision-language-action control for a human-worn device where

the "agent" being acted upon is a human body with its own intent and fall-risk landscape.

(b) Novelty vs. anchors & literature. Differentiates from Molinaro (no vision, no language,

reactive moment estimation), Song ICORR 2025 (vision only personalizes an estimator offline;

no language, no closed-loop torque, no world model), Tagliaferri/Peterson (detection only; no

anticipatory vision, no language), and the Kang stroke T-RO work (proprioceptive online

adaptation, no vision/language). Vs. the broader VLA field: first application to worn assistive

lower-limb robotics; introduces a biomechanical world-model head (XCoM/MoS/fall-risk) rather

than pixel/latent-state reconstruction. It operationalizes the Kang–Mitra–Seethapathi fall-risk-

aware adaptation thesis as an explicit control objective.

(c) System/architecture.

Vision encoder: SigLIP/PaliGemma vision tower (or DINOv2, as in OpenVLA) on a

torso/egocentric camera; optionally a lightweight depth/elevation feature (RealSense) for

terrain geometry. Pretrained features frozen or LoRA-adapted.

Language interface: the VLM backbone (Gemma-2B-class). Language carries (1) clinician

assist-as-needed intent ("provide gentle propulsion, prioritize stability on the paretic side"),

(2) task/terrain priors ("descending stairs," "icy ramp"), (3) risk posture ("conservative —

patient is fall-prone"). Language is the natural channel for clinician-in-the-loop re-tasking

and compositional generalization to unseen terrain/task descriptions.

Action space: gait-phase-parameterized hip torque (peak magnitude, end timing, duration

per the Zhang/Ding human-in-the-loop parameterization) plus a continuous bilateral

torque chunk, generated by a π0-style flow-matching action expert (~300M params)

conditioned on proprioception tokens. Action chunking of ~50 steps with asynchronous re-

planning at a ~100–200 Hz control loop.

World-model / predictive head: a JEPA-/Dreamer-style latent predictor that, from

egocentric vision + proprioception history, forecasts future XCoM/MoS and a fall-risk

scalar over a ~0.5–1 s horizon. This both (i) feeds an anticipatory feature to the action expert

and (ii) supplies a control-barrier-function-style fall-risk gate on torque aggressiveness.

Biomechanics constraints: train/regularize with a neuromusculoskeletal simulator in the

loop (OpenSim/MuJoCo musculoskeletal, as in Park et al. 2026 and Chiu et al. 2025) so

assistance respects muscle-synergy priors and joint limits; reward shaped by EMG

reduction + metabolic surrogate + MoS preservation.

(d) Dataset & hardware plan. Using the group's hip exoskeleton + Humotech/treadmill

perturbation platform:

Collect: time-synced egocentric/torso video, IMU+encoder proprioception, motion-capture

ground truth (for XCoM/MoS labels), EMG, and indirect calorimetry, across level ground,

ramps, stairs, and obstacle/terrain transitions; plus controlled slip/trip and AP/ML

treadmill-belt perturbations. Pair each trial with natural-language captions/instructions

(auto-generated from terrain/task labels + clinician-style templates) to build the language

channel and enable a release as a benchmark.

Baselines: (1) Zero-torque; (2) Molinaro-style unified TCN moment controller

(proprioception only); (3) vision-augmented classifier→assistance (Song/terrain-

classification style); (4) ablations removing language, removing vision, removing the

world-model head.

Perturbation protocol: early-/late-stance slips of varied magnitude (Peterson protocol) and

AP/ML treadmill perturbations; measure detection lead time relative to physiological

reactive-moment onset (Beck framing).

Metrics: metabolic cost (W/kg, %), MoS preservation, fall/stumble event count and recovery

success, perturbation detection lead time (ms vs. physiological onset), joint-moment

tracking RMSE (Nm/kg), EMG reduction, gait-phase error; language generalization (held-

out instructions/terrains); stroke-gait transfer (few-shot).

(e) Evaluation & headline result. Competitive claim: a single vision+language+action policy

that (i) anticipates perturbations and reduces fall/stumble events vs. all baselines, reacting

before physiological reactive-moment onset (Beck et al. motivation); (ii) preserves metabolic

benefit on par with the unified controller on level ground/ramps (target: within noise of the ~5– arxiv (https://arxiv.org/pdf/2509.07962)

13% level-ground and ~10–18% incline reductions Molinaro reported); and (iii) generalizes

zero-/few-shot to new terrains and to stroke gait via language conditioning, without retraining

the torque controller. The figure-1 story: "re-task a worn exoskeleton with a sentence, and it stays

safe because it predicts your fall risk from what it sees."

(f) Anticipated reviewer objections & preemptions.

"Is language necessary or decorative?" Ablate: show language conditioning yields

measurable zero-shot terrain/stroke transfer and clinician-controllable assist-as-needed

behavior that proprioception-only baselines cannot. Frame language as the clinician/HITL

interface.

"VLA is overkill for torque control." Position the contribution as the predictive fall-risk world

model + cross-task/terrain generalization, not raw torque tracking; show generalization a

TCN cannot match.

"Safety of a large model in the loop." Dual-system design: a fast low-level safety filter / CBF

gated by predicted MoS runs at high rate; the VLA re-plans chunks asynchronously. Report

the latency budget and fallback policy.

"N is small / single lab." Standard for hardware exo papers; emphasize within-subject

perturbation statistics, real-robot deployment, and a released dataset (NeurIPS D&B angle).

"Compute / reproducibility." QLoRA fine-tuning on a single A100; prototype on T4/A10 with

a frozen backbone first.

(g) Why fusion is necessary, not incidental. Vision supplies anticipation (terrain/perturbation

cues before bodily deviation) that proprioception cannot; language supplies intent and

compositional re-tasking (clinician assist-as-needed, risk posture, unseen-terrain priors) that

vision cannot encode; action (torque) is the only thing that changes the wearer's biomechanics.

The fall-risk world model only becomes controllable when all three are present — vision to

predict, language to set the risk/intent trade-off, action to intervene. Remove any modality and

either anticipation, controllability, or efficacy collapses.

Compute & prototyping

Single A100 (80GB) for QLoRA fine-tuning of a 3B-class VLM + flow-matching head; fewA10/T4

GPUs for the frozen-backbone prototype and the world-model head (small JEPA/RSSM).

Prototype offline on collected data (open-loop torque prediction + MoS forecasting) before

closed-loop hardware deployment.

Backup ideas (sketched)

B1 — "Biomechanical World Model" (NeurIPS/ICLR, simpler): drop language; train a

Dreamer/V-JEPA-style latent world model that predicts XCoM/MoS and fall risk from

egocentric vision + IMU, used for model-predictive anticipatory assistance. Cleaner ML

story, less HRI risk; weaker on the "fusion" mandate.

B2 — "Language-personalized assist-as-needed for stroke" (T-RO/TNSRE/ICORR):

clinician natural-language instructions → assistance-parameter adaptation on top of the

Kang stroke online-adaptation framework, with pose-estimation vision for asymmetry

monitoring. Strong clinical translation; lighter on novelty for ML venues.

Recommendations

1. Stage 0 (weeks): Offline proof-of-concept on existing logged data — train the world-model

head to forecast MoS/fall-risk from vision+IMU; show it beats proprioception-only and the

angular-momentum benchmark (Tagliaferri's 95.5%/33.1%) on perturbation anticipation.

Proceed if it yields predictive lead time before physiological onset at useful accuracy.

2. Stage 1: QLoRA fine-tune the VLA on collected trials with auto-generated language;

validate open-loop torque + chunked action prediction against the unified-controller

baseline. Proceed if moment-tracking RMSE and the metabolic surrogate match the TCN

(≈0.142 Nm/kg) within noise.

3. Stage 2: Closed-loop hardware with the safety filter; run slip/trip + treadmill perturbation

protocols; measure fall/stumble reduction and detection lead time. Threshold for a top-tier

submission: statistically significant fall-event reduction AND preserved metabolic benefit

AND nonzero language/terrain generalization.

4. Venue routing: Lead for CoRL (real-robot learning, language-conditioned) or RSS; if the

dataset is strong, a parallel NeurIPS Datasets & Benchmarks submission (first vision-

language-exoskeleton dataset). Clinical-translation results → Science Robotics /IEEE T-

RO / TNSRE. Calibrate to CoRL 2025 norms (real-hardware demos, ablation-heavy,

released code).

5. De-risk the negative claim: before asserting "first VLA for worn exoskeletons," do a final

manual scan of late-2025/2026 arXiv/CoRL/ICRA — the VLA field moves fast.

Caveats

The "no prior VLA for worn lower-limb exo" claim is based on current surveys and targeted

search; verify against the newest preprints before claiming primacy.

Hardware exo studies are small-N and single-lab; statistical power for fall-event reduction

must be designed carefully (within-subject design, many perturbation trials).

Large-model in-the-loop latency is a real risk; the dual-system safety architecture is

essential and must be validated empirically.

Metabolic and EMG measurements are noisy; use established ML surrogates (e.g., Slade-

style real-time estimation) and adequate trial counts.

Tagliaferri figures differ between the pilot preprint (98.8%/23.1%, 5 subjects) and the

published ICORR 2025 version (95.5%/33.1%, 9 subjects); cite the published numbers.

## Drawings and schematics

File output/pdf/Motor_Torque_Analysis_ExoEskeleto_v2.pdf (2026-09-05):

MECHANICAL DESIGN ANALYSIS

# Euler-Lagrange joint and motor torque analysis

## ExoEskeleto lower-limb exoskeleton - knee-dominant actuator sizing grounded in the updated manufacturing drawing and supplied CAD

gait.

REFERENCE USER

### 80 kg

FRAME

### 6.49 kg Al 6061-T6

GAIT INPUT

### 2.4 s / 60 frames

ANALYSIS DATE

### 28 July 2026

# Knee 120 N m peak | Ankle 60 N m peak

### Passive hip

### 0 N m motor

Reaction load remains and must be carried structurally.

### Knee - highest

120 N m peak

60 N m provisional continuous output.

### Ankle

### 60 N m peak

30 N m provisional continuous output.

SELECTED OUTPUT RATINGS - EACH SIDE

Hip motor torque is 0 N m because the current manufacturing drawing defines the hip as a passive pivot.

Engineering sizing study only. Complete native CAD mass properties, measured ground-reaction forces, structural FEA, gearbox life analysis, thermal validation, and instrumented bench testing before human use.

ExoEskeleto Euler-Lagrange torque analysis | 1 / 8

# 1. Evidence audit and model basis

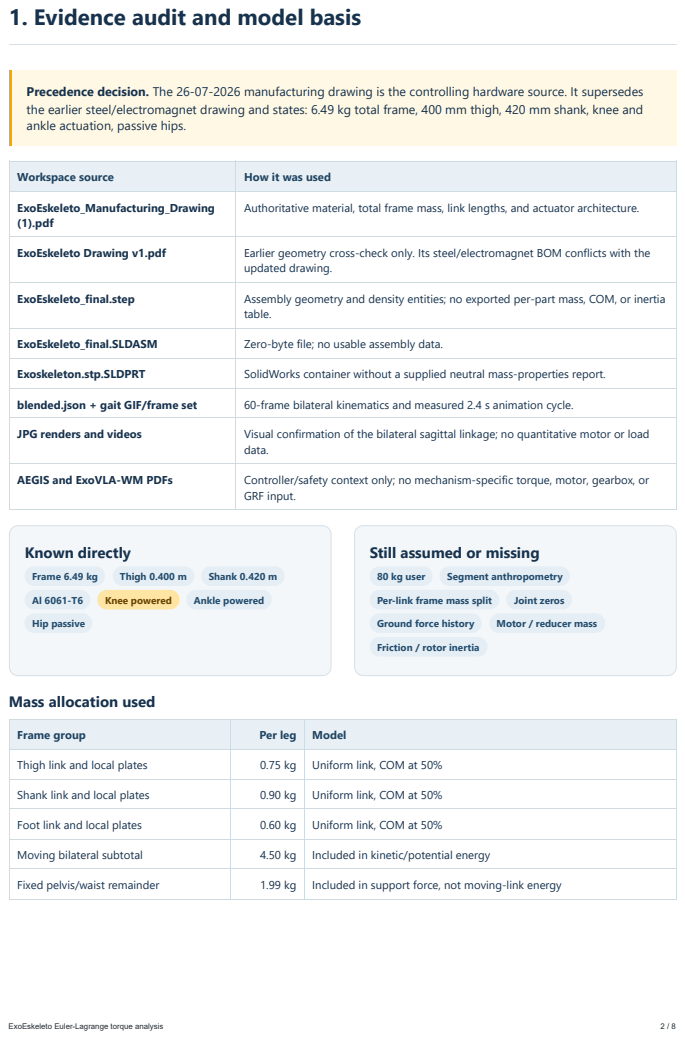
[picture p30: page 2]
Known directly; Frame 6.49 kg; Thigh 0.400 m; Shank 0.420 m; Knee powered; Ankle powered; Hip passive; 80 kg user; Segment anthropometry; Per-link frame mass split; Joint zeros; Ground force history; Motor / reducer mass

Precedence decision. The 26-07-2026 manufacturing drawing is the controlling hardware source. It supersedes
the earlier steel/electromagnet drawing and states: 6.49 kg total frame, 400 mm thigh, 420 mm shank, knee and
ankle actuation, passive hips.

Workspace source | How it was used

ExoEskeleto_Manufacturing_Drawing (1).pdf | Authoritative material, total frame mass, link lengths, and actuator architecture.

ExoEskeleto Drawing v1.pdf | Earlier geometry cross-check only. Its steel/electromagnet BOM conflicts with the updated drawing.

ExoEskeleto_final.step | Assembly geometry and density entities; no exported per-part mass, COM, or inertia table.

ExoEskeleto_final.SLDASM | Zero-byte file; no usable assembly data.

Exoskeleton.stp.SLDPRT | SolidWorks container without a supplied neutral mass-properties report.

blended.json + gait GIF/frame set | 60-frame bilateral kinematics and measured 2.4 s animation cycle.

JPG renders and videos | Visual confirmation of the bilateral sagittal linkage; no quantitative motor or load data.

AEGIS and ExoVLA-WM PDFs | Controller/safety context only; no mechanism-specific torque, motor, gearbox, or GRF input.

Still assumed or missing

Friction / rotor inertia

Mass allocation used

Frame group | Per leg | Model

Thigh link and local plates | 0.75 kg | Uniform link, COM at 50%

Shank link and local plates | 0.90 kg | Uniform link, COM at 50%

Foot link and local plates | 0.60 kg | Uniform link, COM at 50%

Moving bilateral subtotal | 4.50 kg | Included in kinetic/potential energy

Fixed pelvis/waist remainder | 1.99 kg | Included in support force, not moving-link energy

# 2. Euler-Lagrange formulation

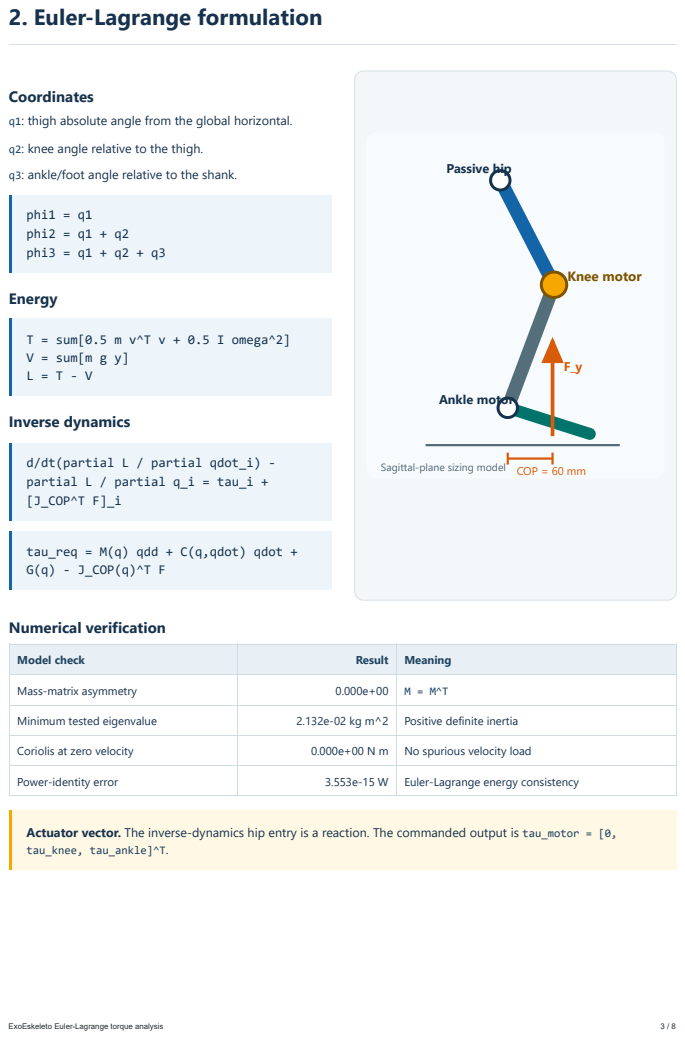
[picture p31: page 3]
phi1 = q1 phi2 = q1 + q2 phi3 = q1 + q2 + q3; Energy; T = sum[0.5 m v^T v + 0.5 I omega^2] V = sum[m g y] L = T - V; Inverse dynamics; Passive hip; Knee motor; Ankle motor; Numerical verification

Coordinates
q1: thigh absolute angle from the global horizontal.
q2: knee angle relative to the thigh.
q3: ankle/foot angle relative to the shank.

d/dt(partial L / partial qdot_i) -
partial L / partial q_i = tau_i +
[J_COP^T F]_i

Sagittal-plane sizing model COP = 60 mm

tau_req = M(q) qdd + C(q,qdot) qdot +
G(q) - J_COP(q)^T F

Model check | Result | Meaning

Mass-matrix asymmetry | 0.000e+00 | M = M^T

Minimum tested eigenvalue | 2.132e-02 kg m^2 | Positive definite inertia

Coriolis at zero velocity | 0.000e+00 N m | No spurious velocity load

Power-identity error | 3.553e-15 W | Euler-Lagrange energy consistency

Actuator vector. The inverse-dynamics hip entry is a reaction. The commanded output is tau_motor = [0,
tau_knee, tau_ankle]^T.
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

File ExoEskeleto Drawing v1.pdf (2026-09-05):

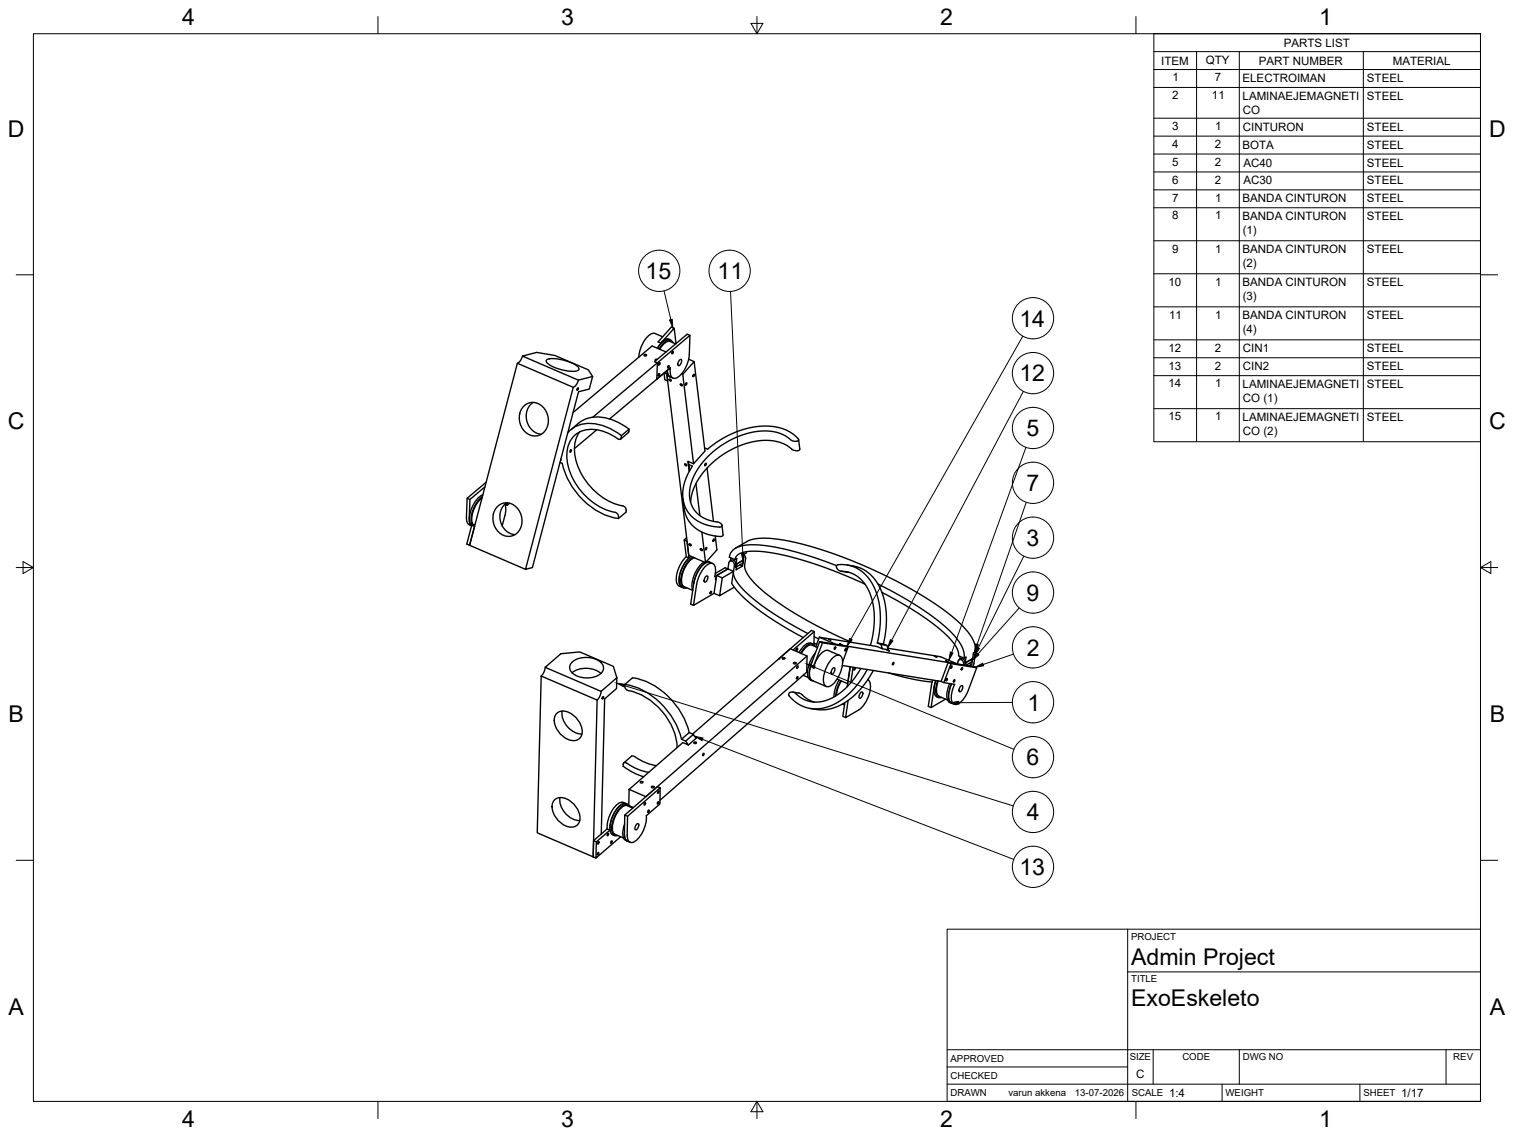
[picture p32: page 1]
BACD BACD; SIZE; CODE; DWG NO; REV; varun akkena 13-07-2026; Admin Project; PARTS LIST

ITEM | QTY 11 7 | ELECTROIMAN LAMINAEJEMAGNETI PART NUMBER | STEEL 2 MATERIAL 1

2 2 2 1 1 1 | BOTA BANDA CINTURON BANDA CINTURON CINTURON AC40 AC30 | STEEL 3 STEEL 4 STEEL 5 STEEL 6 STEEL 7 STEEL 8

1 | BANDA CINTURON (1) | STEEL 9

(2) | STEEL

10 | 1 | BANDA CINTURON (3) | STEEL

11 | 1 | BANDA CINTURON (4) | STEEL

12 | 2 | CIN1 | STEEL
13 | 2 | CIN2 | STEEL
14 | 1 | LAMINAEJEMAGNETI CO (1) | STEEL

15 | 1 | LAMINAEJEMAGNETI CO (2) | STEEL

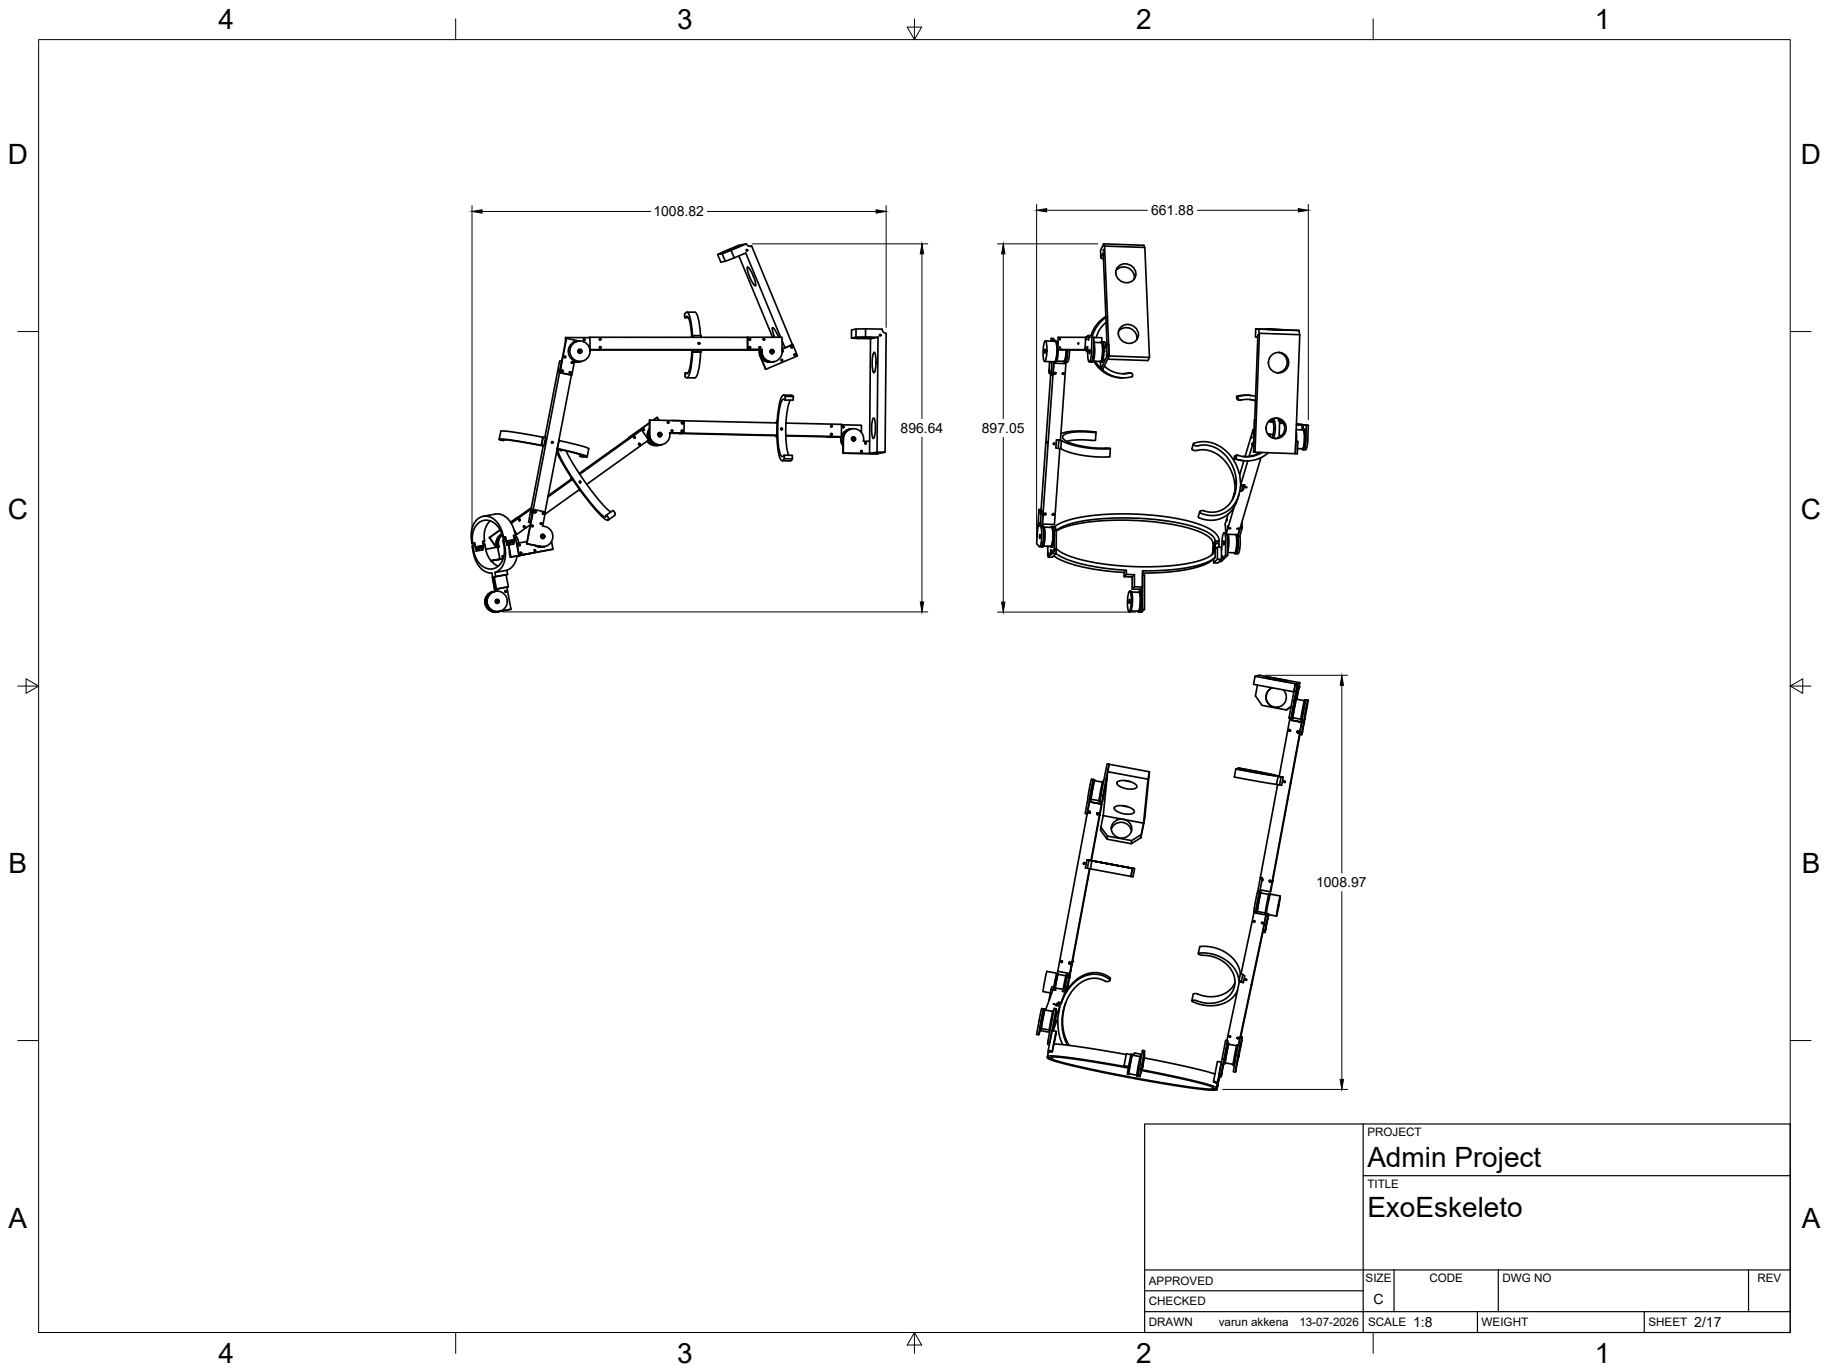
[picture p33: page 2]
Admin Project

varun akkena 13-07-2026 | 1:8 | 2/17

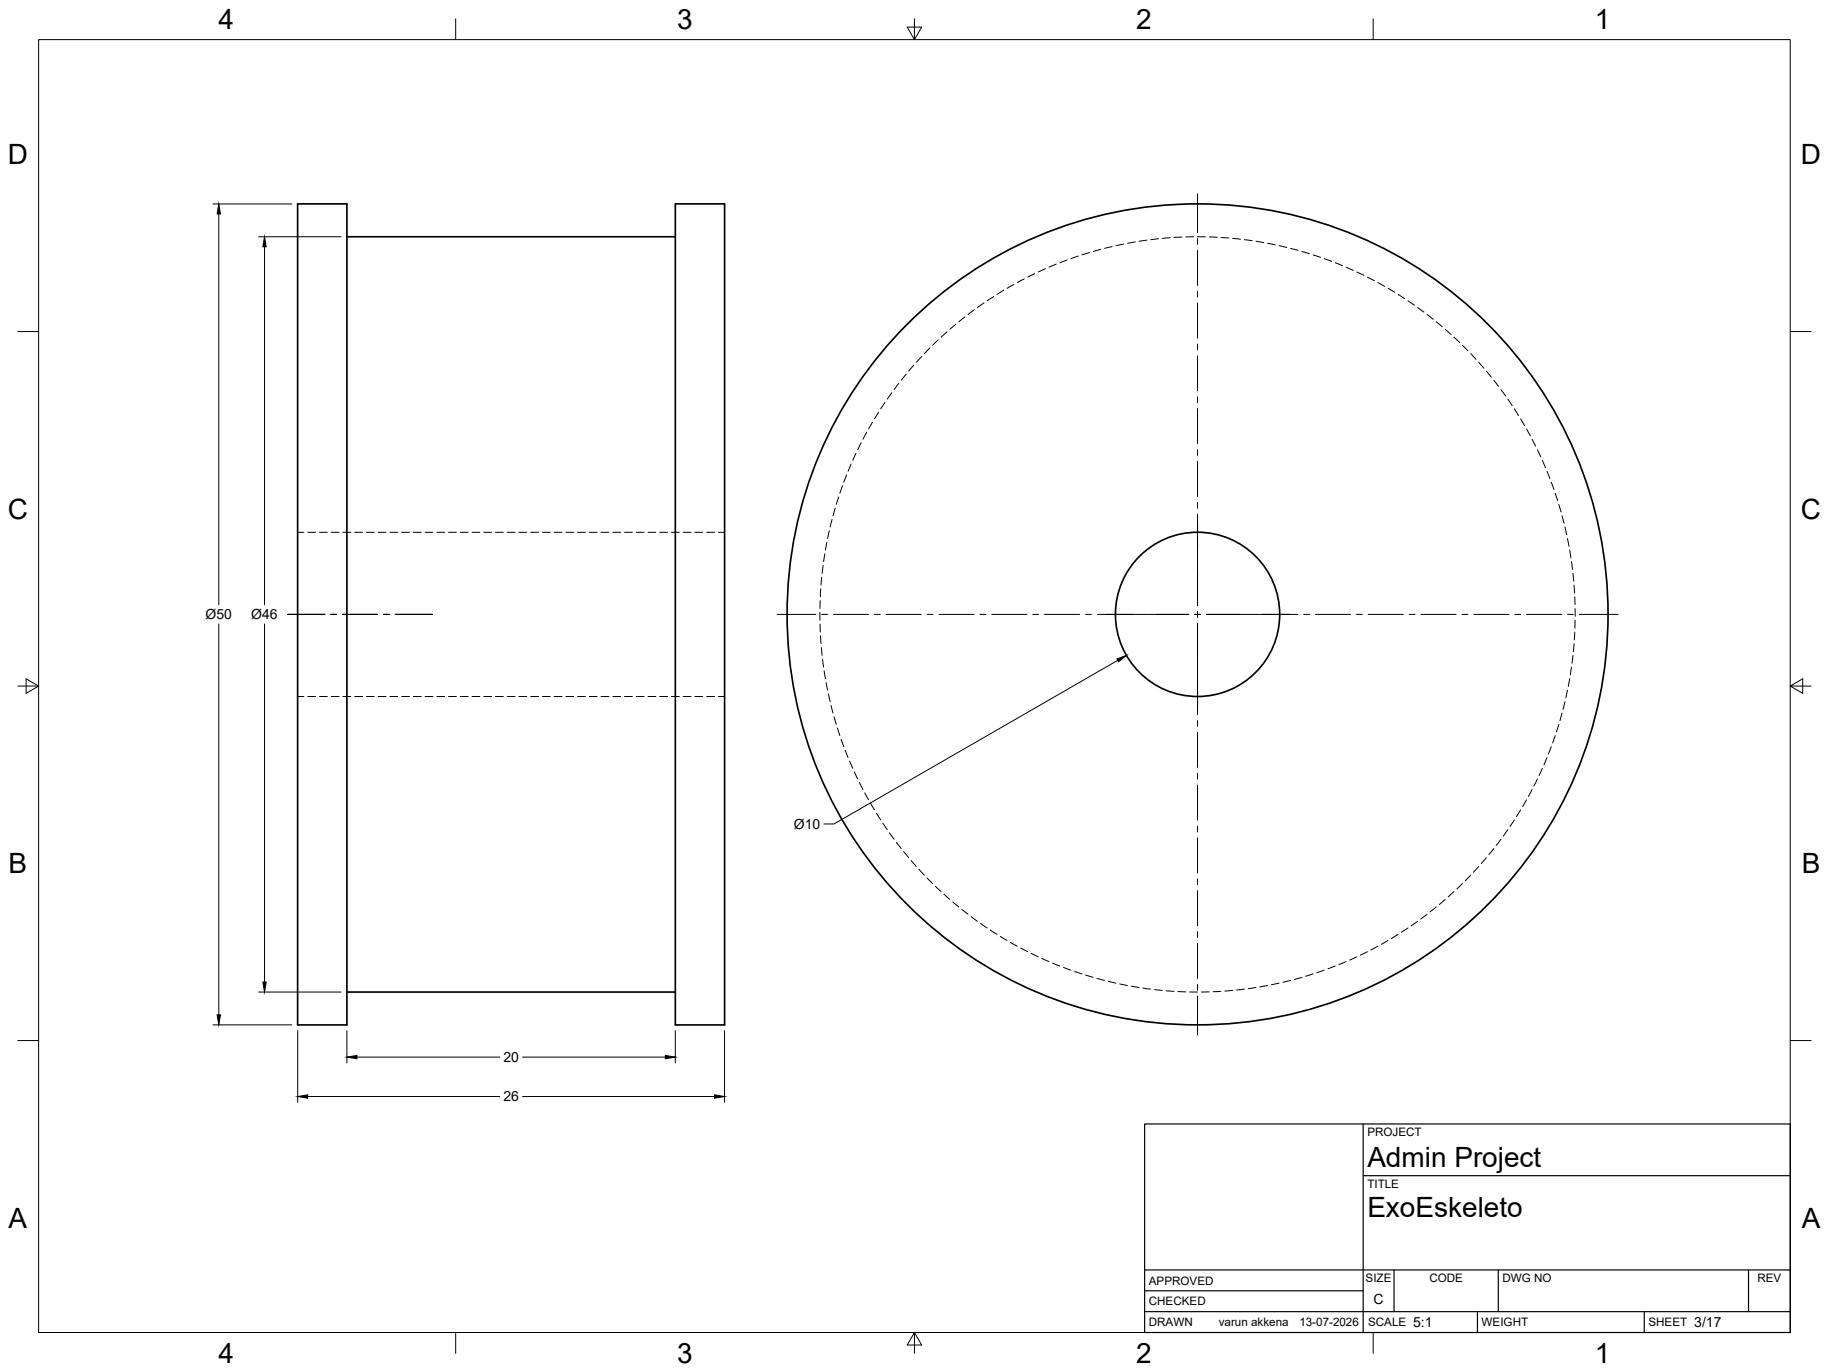
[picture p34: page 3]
varun akkena 13-07-2026; Admin Project

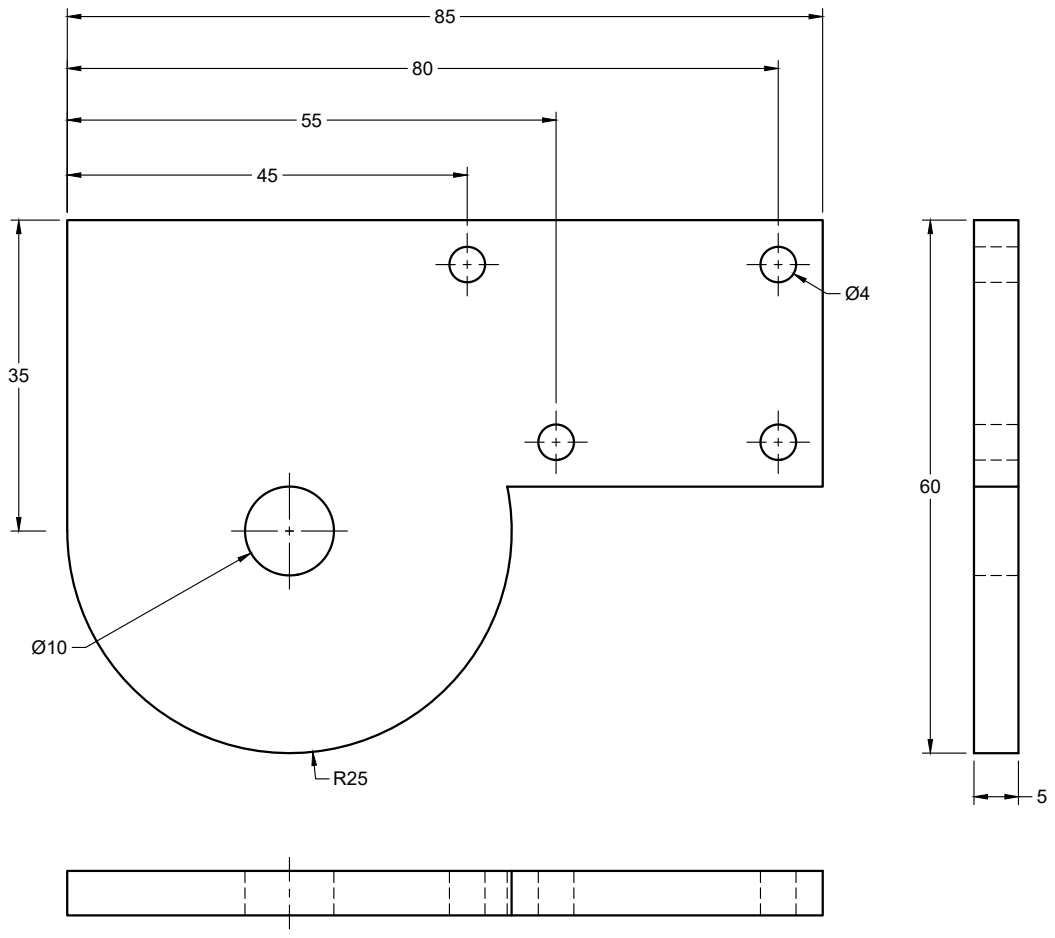
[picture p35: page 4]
varun akkena 13-07-2026; Admin Project

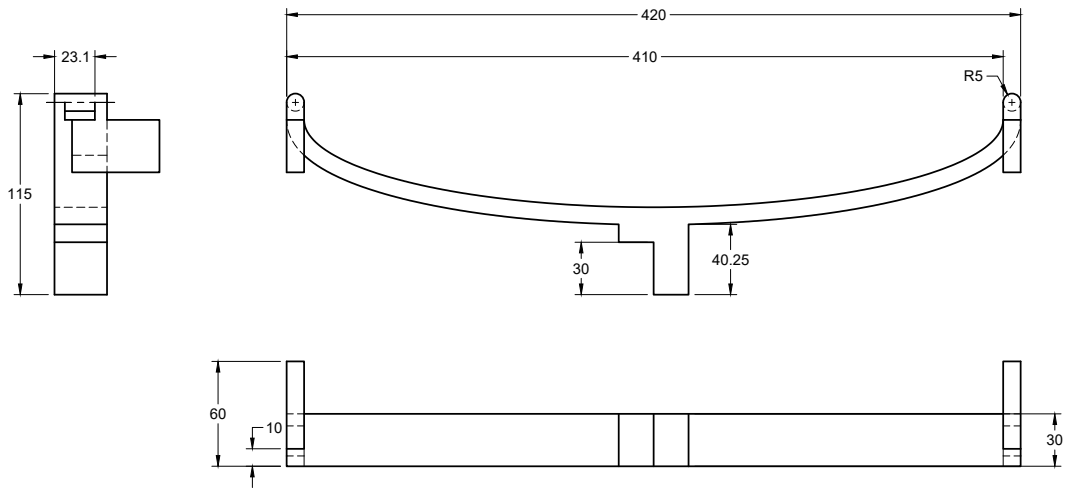
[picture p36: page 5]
varun akkena 13-07-2026; Admin Project

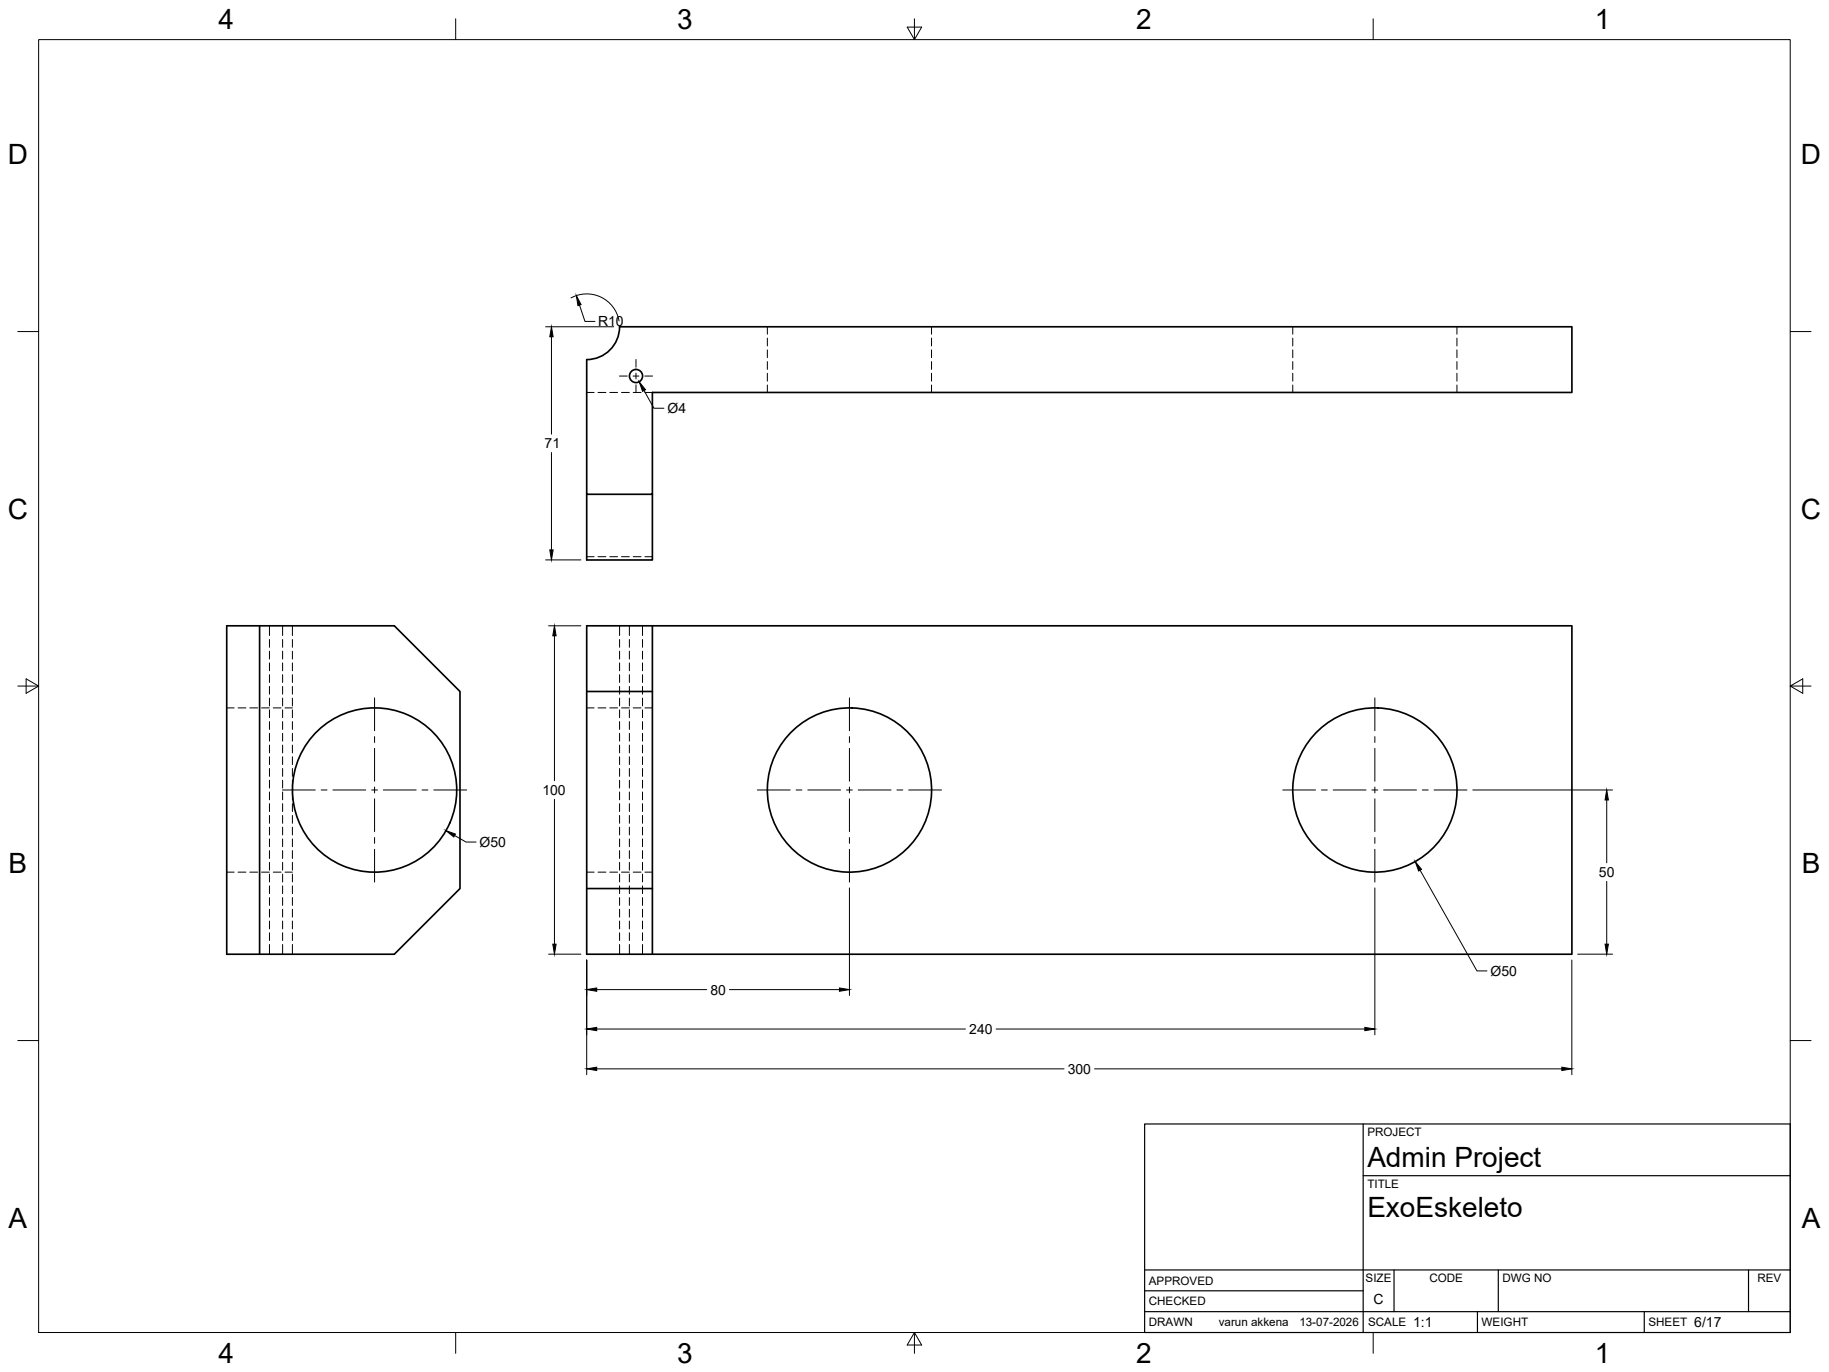
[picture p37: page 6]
varun akkena 13-07-2026; Admin Project

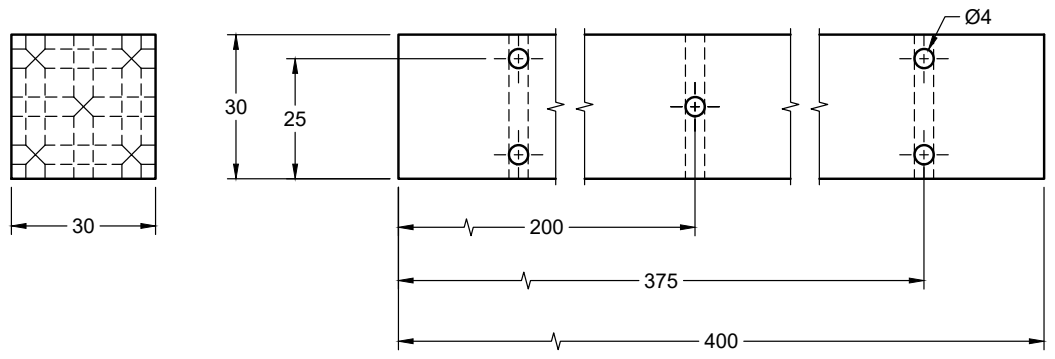
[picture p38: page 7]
varun akkena 13-07-2026; Admin Project

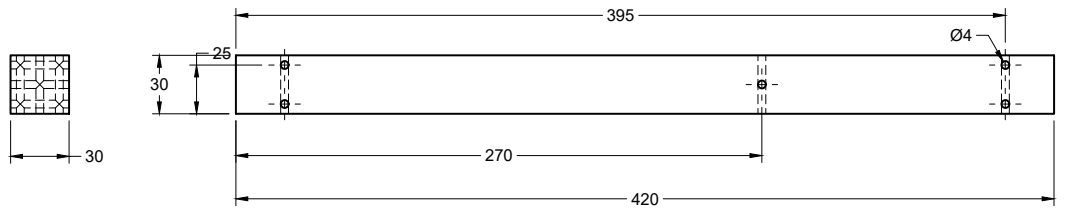
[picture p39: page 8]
varun akkena 13-07-2026; Admin Project

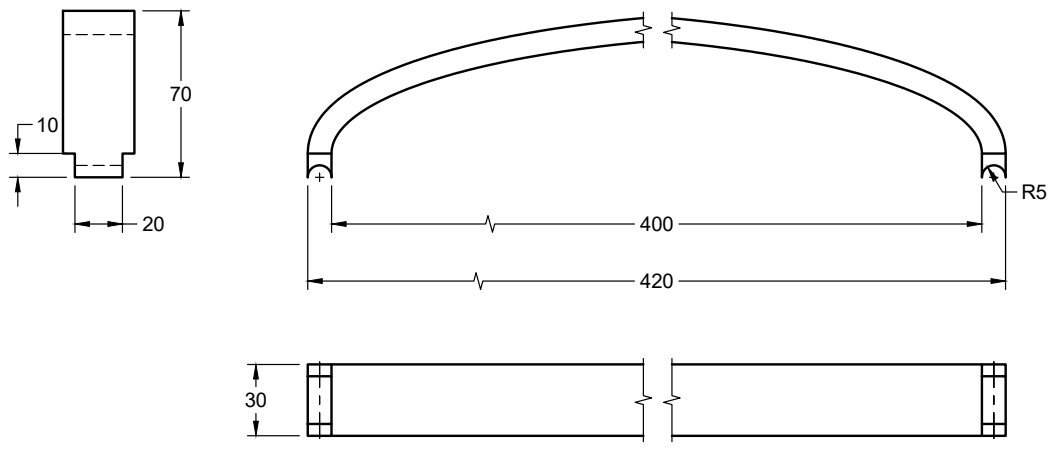
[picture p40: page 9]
varun akkena 13-07-2026; Admin Project

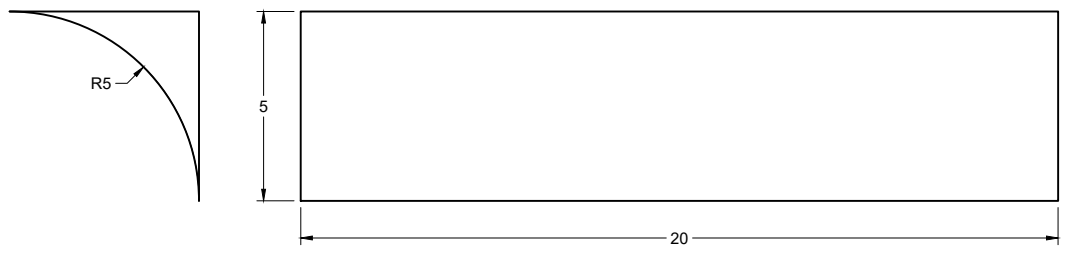
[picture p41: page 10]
varun akkena 13-07-2026; Admin Project

varun akkena 13-07-2026; Admin Project

varun akkena 13-07-2026; Admin Project

varun akkena 13-07-2026; Admin Project

varun akkena 13-07-2026; Admin Project

varun akkena 13-07-2026; Admin Project

varun akkena 13-07-2026; Admin Project

varun akkena 13-07-2026; Admin Project

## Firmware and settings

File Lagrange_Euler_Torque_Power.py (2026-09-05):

"""Euler-Lagrange torque analysis for the ExoEskeleto lower-limb frame.

The model is a sagittal-plane, three-link human-exoskeleton leg:

    q1 - thigh absolute angle measured from the global horizontal
    q2 - knee angle relative to the thigh
    q3 - ankle/foot angle relative to the shank

The updated manufacturing drawing states that the hip is passive and the knee
and ankle house the actuators.  The inverse-dynamics hip result is therefore a
required passive joint/pelvis reaction, not a motor command.

Two load cases are evaluated:

1. Swing: kinematics from ``ExoWalk_frames/blended.json`` over the 2.4 s GIF
   cycle, with no ground reaction force.
2. Bent-knee support / sit-to-stand: 60 degree thigh and shank inclination,
   1.2 body-weight total vertical support shared equally by both feet, and a
   60 mm centre-of-pressure offset from the ankle.

The script writes reproducible CSV, JSON, and PNG outputs when ``--write`` is
used.  It intentionally keeps unprovided motor mass, friction, and rotor
inertia out of the nominal result and calls those omissions out in the report.
"""

from __future__ import annotations

import argparse
import csv
import json
import math
from dataclasses import asdict, dataclass
from pathlib import Path
from typing import Iterable, Sequence

import matplotlib

matplotlib.use("Agg")
import matplotlib.pyplot as plt
import numpy as np
from scipy.signal import savgol_filter


G_ACCEL = 9.81
JOINT_NAMES = ("Hip reaction", "Knee motor", "Ankle motor")
SHORT_JOINT_NAMES = ("Hip", "Knee", "Ankle")

# Updated manufacturing drawing, Note 5.2.
LINK_LENGTHS = np.array([0.400, 0.420, 0.260], dtype=float)

# Dempster-style body-segment estimates retained from the v1 calculation.
HUMAN_MASS_FRACTIONS = np.array([0.1000, 0.0465, 0.0145], dtype=float)
HUMAN_COM_FRACTIONS = np.array([0.433, 0.433, 0.500], dtype=float)
HUMAN_GYRATION_FRACTIONS = np.array([0.323, 0.302, 0.475], dtype=float)

# The drawing gives only the 6.49 kg total frame mass, not per-part mass
# properties.  The nominal moving-link allocation below totals 2.25 kg/leg;
# the remaining 1.99 kg is assigned to the fixed pelvis/waist structure.
DEFAULT_EXO_LINK_MASSES = np.array([0.750, 0.900, 0.600], dtype=float)
DEFAULT_FRAME_MASS = 6.49

DEFAULT_USER_MASS = 80.0
DEFAULT_CYCLE_TIME = 2.4
DEFAULT_COP_DISTANCE = 0.060
DEFAULT_SUPPORT_MULTIPLIER_PER_LEG = 0.60  # 1.2 BW total / two legs
DEFAULT_ENGINEERING_FACTOR = 1.50

DEFAULT_REDUCTION_RATIOS = {"knee": 80.0, "ankle": 60.0}
DEFAULT_GEAR_EFFICIENCY = {"knee": 0.75, "ankle": 0.75}

GAIT_JOINT_MAP = {
    "left": ("Revolute 4", "Revolute 30", "Revolute 67"),
    "right": ("Revolute 2", "Revolute 19", "Revolute 29"),
}


@dataclass(frozen=True)
class RigidComponent:
    """A rigid mass component attached to one serial link."""

    name: str
    link: int
    mass: float
    com_from_proximal: float
    inertia_about_com: float


@dataclass(frozen=True)
class JointSummary:
    """Peak and RMS values for one gait-side/joint combination."""

    peak_abs_torque_nm: float
    rms_torque_nm: float
    peak_abs_speed_rad_s: float
    peak_abs_accel_rad_s2: float
    peak_abs_power_w: float
    rms_power_w: float


@dataclass(frozen=True)
class MotorRating:
    joint: str
    continuous_output_nm: float
    peak_output_nm: float
    reduction_ratio: float
    efficiency: float
    continuous_motor_nm: float
    peak_motor_nm: float
    measured_peak_joint_speed_rad_s: float
    measured_peak_motor_rpm: float


def build_components(
    user_mass: float,
    exo_link_masses: Sequence[float] = DEFAULT_EXO_LINK_MASSES,
) -> list[RigidComponent]:
    """Return human and frame components for one leg."""

    exo_link_masses = np.asarray(exo_link_masses, dtype=float)
    if exo_link_masses.shape != (3,) or np.any(exo_link_masses < 0.0):
        raise ValueError("exo_link_masses must contain three non-negative values")

    human_masses = HUMAN_MASS_FRACTIONS * user_mass
    components: list[RigidComponent] = []
    uniform_rod_gyration_fraction = 1.0 / math.sqrt(12.0)

    for index, length in enumerate(LINK_LENGTHS):
        human_mass = float(human_masses[index])
        human_com = float(HUMAN_COM_FRACTIONS[index] * length)
        human_inertia = float(
            human_mass * (HUMAN_GYRATION_FRACTIONS[index] * length) ** 2
        )
        components.append(
            RigidComponent(
                name=f"human_{SHORT_JOINT_NAMES[index].lower()}_segment",
                link=index,
                mass=human_mass,
                com_from_proximal=human_com,
                inertia_about_com=human_inertia,
            )
        )

        exo_mass = float(exo_link_masses[index])
        exo_com = float(0.5 * length)
        exo_inertia = float(
            exo_mass * (uniform_rod_gyration_fraction * length) ** 2
        )
        components.append(
            RigidComponent(
                name=f"exo_{SHORT_JOINT_NAMES[index].lower()}_link",
                link=index,
                mass=exo_mass,
                com_from_proximal=exo_com,
                inertia_about_com=exo_inertia,
            )
        )

    return components


def cumulative_angles(q: Sequence[float]) -> np.ndarray:
    """Return the three absolute link angles."""

    q_array = np.asarray(q, dtype=float)
    return np.cumsum(q_array)


def component_com_jacobian(
    component: RigidComponent,
    q: Sequence[float],
) -> np.ndarray:
    """Return the 2 x 3 translational Jacobian of a component COM."""

    phi = cumulative_angles(q)
    jacobian = np.zeros((2, 3), dtype=float)
    link_index = component.link

    for joint in range(link_index + 1):
        for link in range(joint, link_index):
            jacobian[0, joint] -= LINK_LENGTHS[link] * math.sin(phi[link])
            jacobian[1, joint] += LINK_LENGTHS[link] * math.cos(phi[link])

        jacobian[0, joint] -= component.com_from_proximal * math.sin(
            phi[link_index]
        )
        jacobian[1, joint] += component.com_from_proximal * math.cos(
            phi[link_index]
        )

    return jacobian


def cop_jacobian(
    q: Sequence[float],
    cop_distance: float = DEFAULT_COP_DISTANCE,
) -> np.ndarray:
    """Return the 2 x 3 Jacobian at the foot centre of pressure.

    ``cop_distance`` is measured forward from the ankle along the foot link.
    It is not assumed to be the toe position.
    """

    phi = cumulative_angles(q)
    jacobian = np.zeros((2, 3), dtype=float)

    for joint in range(3):
        for link in range(joint, 2):
            jacobian[0, joint] -= LINK_LENGTHS[link] * math.sin(phi[link])
            jacobian[1, joint] += LINK_LENGTHS[link] * math.cos(phi[link])

        jacobian[0, joint] -= cop_distance * math.sin(phi[2])
        jacobian[1, joint] += cop_distance * math.cos(phi[2])

    return jacobian


def mass_matrix(
    q: Sequence[float],
    components: Iterable[RigidComponent],
) -> np.ndarray:
    """Return M(q) in kg m^2."""

    matrix = np.zeros((3, 3), dtype=float)

    for component in components:
        jacobian = component_com_jacobian(component, q)
        matrix += component.mass * jacobian.T @ jacobian
        matrix[
            : component.link + 1,
            : component.link + 1,
        ] += component.inertia_about_com

    return matrix


def gravity_vector(
    q: Sequence[float],
    components: Iterable[RigidComponent],
) -> np.ndarray:
    """Return G(q) = partial(V)/partial(q) in N m."""

    vector = np.zeros(3, dtype=float)

    for component in components:
        jacobian = component_com_jacobian(component, q)
        vector += component.mass * G_ACCEL * jacobian[1, :]

    return vector


def mass_matrix_derivatives(
    q: Sequence[float],
    components: Sequence[RigidComponent],
    step: float = 1.0e-6,
) -> np.ndarray:
    """Return dM/dq_k as an array with shape (3, 3, 3)."""

    q_array = np.asarray(q, dtype=float)
    derivatives = np.zeros((3, 3, 3), dtype=float)

    for coordinate in range(3):
        q_plus = q_array.copy()
        q_minus = q_array.copy()
        q_plus[coordinate] += step
        q_minus[coordinate] -= step
        derivatives[coordinate] = (
            mass_matrix(q_plus, components)
            - mass_matrix(q_minus, components)
        ) / (2.0 * step)

    return derivatives


def coriolis_vector(
    q: Sequence[float],
    qd: Sequence[float],
    components: Sequence[RigidComponent],
) -> np.ndarray:
    """Return C(q, qdot) qdot from the Christoffel symbols."""

    qd_array = np.asarray(qd, dtype=float)
    derivatives = mass_matrix_derivatives(q, components)
    vector = np.zeros(3, dtype=float)

    for output in range(3):
        for j in range(3):
            for k in range(3):
                gamma = 0.5 * (
                    derivatives[k, output, j]
                    + derivatives[j, output, k]
                    - derivatives[output, j, k]
                )
                vector[output] += gamma * qd_array[j] * qd_array[k]

    return vector


def generalized_external_force(
    q: Sequence[float],
    foot_force_xy: Sequence[float],
    cop_distance: float,
) -> np.ndarray:
    """Return J_COP(q)^T F in N m."""

    jacobian = cop_jacobian(q, cop_distance)
    return jacobian.T @ np.asarray(foot_force_xy, dtype=float)


def inverse_dynamics(
    q: Sequence[float],
    qd: Sequence[float],
    qdd: Sequence[float],
    components: Sequence[RigidComponent],
    foot_force_xy: Sequence[float] = (0.0, 0.0),
    cop_distance: float = DEFAULT_COP_DISTANCE,
) -> dict[str, np.ndarray]:
    """Evaluate tau = M qdd + C qdot + G - J_COP^T F."""

    q_array = np.asarray(q, dtype=float)
    qd_array = np.asarray(qd, dtype=float)
    qdd_array = np.asarray(qdd, dtype=float)

    matrix = mass_matrix(q_array, components)
    inertia = matrix @ qdd_array
    coriolis = coriolis_vector(q_array, qd_array, components)
    gravity = gravity_vector(q_array, components)
    external = generalized_external_force(
        q_array,
        foot_force_xy,
        cop_distance,
    )
    torque = inertia + coriolis + gravity - external
    power = torque * qd_array

    return {
        "mass_matrix": matrix,
        "inertia": inertia,
        "coriolis": coriolis,
        "gravity": gravity,
        "external": external,
        "torque": torque,
        "power": power,
    }


def validate_model(components: Sequence[RigidComponent]) -> dict[str, float]:
    """Run numerical consistency checks on the Euler-Lagrange model."""

    q = np.deg2rad(np.array([-67.0, 38.0, 25.0]))
    qd = np.array([0.8, -1.2, 0.6])
    qdd = np.array([1.1, -0.7, 0.9])

    matrix = mass_matrix(q, components)
    symmetry_error = float(np.max(np.abs(matrix - matrix.T)))
    minimum_eigenvalue = float(np.min(np.linalg.eigvalsh(matrix)))
    zero_velocity_coriolis = float(
        np.max(np.abs(coriolis_vector(q, np.zeros(3), components)))
    )

    derivatives = mass_matrix_derivatives(q, components)
    matrix_dot = sum(derivatives[k] * qd[k] for k in range(3))
    coriolis = coriolis_vector(q, qd, components)
    lagrange_power = float(
        qd
        @ (
            matrix @ qdd
            + coriolis
            + gravity_vector(q, components)
        )
    )
    energy_rate = float(
        qd @ matrix @ qdd
        + 0.5 * qd @ matrix_dot @ qd
        + gravity_vector(q, components) @ qd
    )
    power_identity_error = abs(lagrange_power - energy_rate)

    if symmetry_error > 1.0e-9:
        raise RuntimeError(f"Mass matrix symmetry check failed: {symmetry_error}")
    if minimum_eigenvalue <= 0.0:
        raise RuntimeError(
            f"Mass matrix positive-definiteness check failed: {minimum_eigenvalue}"
        )
    if zero_velocity_coriolis > 1.0e-10:
        raise RuntimeError(
            f"Zero-velocity Coriolis check failed: {zero_velocity_coriolis}"
        )
    if power_identity_error > 1.0e-7:
        raise RuntimeError(
            f"Euler-Lagrange power identity failed: {power_identity_error}"
        )

    return {
        "mass_matrix_symmetry_error": symmetry_error,
        "minimum_mass_matrix_eigenvalue": minimum_eigenvalue,
        "zero_velocity_coriolis_error": zero_velocity_coriolis,
        "lagrange_power_identity_error": power_identity_error,
    }


def _odd_window(sample_count: int, desired: int = 9) -> int:
    window = min(desired, sample_count - (1 - sample_count % 2))
    if window < 5:
        raise ValueError("At least five gait samples are required")
    return window if window % 2 else window - 1


def load_gait_coordinates(
    gait_json: Path,
    cycle_time: float,
) -> tuple[np.ndarray, dict[str, dict[str, np.ndarray]]]:
    """Map the CAD revolute histories to q, qdot, and qdd.

    The first animation frame is treated as the neutral calibration pose:
    thigh vertical, knee extended, and foot horizontal.  This is the only
    defensible mapping available because the JSON contains no joint-zero or
    axis-sign metadata.
    """

    payload = json.loads(gait_json.read_text(encoding="utf-8"))
    angles = payload["angles"]
    sample_count = int(payload["frames"])
    time = np.arange(sample_count, dtype=float) * cycle_time / sample_count
    sample_period = cycle_time / sample_count
    window = _odd_window(sample_count)
    result: dict[str, dict[str, np.ndarray]] = {}

    neutral = np.deg2rad(np.array([-90.0, 0.0, 90.0]))

    for side, joint_names in GAIT_JOINT_MAP.items():
        raw = np.vstack(
            [
                np.unwrap(np.deg2rad(np.asarray(angles[name], dtype=float)))
                for name in joint_names
            ]
        ).T
        q = raw - raw[0, :] + neutral
        qd = savgol_filter(
            q,
            window_length=window,
            polyorder=3,
            deriv=1,
            delta=sample_period,
            axis=0,
            mode="wrap",
        )
        qdd = savgol_filter(
            q,
            window_length=window,
            polyorder=3,
            deriv=2,
            delta=sample_period,
            axis=0,
            mode="wrap",
        )
        result[side] = {"q": q, "qd": qd, "qdd": qdd}

    return time, result


def evaluate_gait(
    gait_json: Path,
    cycle_time: float,
    components: Sequence[RigidComponent],
) -> tuple[
    np.ndarray,
    dict[str, dict[str, np.ndarray]],
    dict[str, dict[str, JointSummary]],
]:
    """Run swing-phase inverse dynamics for both animated legs."""

    time, coordinates = load_gait_coordinates(gait_json, cycle_time)
    detailed: dict[str, dict[str, np.ndarray]] = {}
    summary: dict[str, dict[str, JointSummary]] = {}

    for side, motion in coordinates.items():
        torque_rows = []
        power_rows = []
        inertia_rows = []
        coriolis_rows = []
        gravity_rows = []

        for q, qd, qdd in zip(motion["q"], motion["qd"], motion["qdd"]):
            values = inverse_dynamics(q, qd, qdd, components)
            torque_rows.append(values["torque"])
            power_rows.append(values["power"])
            inertia_rows.append(values["inertia"])
            coriolis_rows.append(values["coriolis"])
            gravity_rows.append(values["gravity"])

        torque = np.asarray(torque_rows)
        power = np.asarray(power_rows)
        detailed[side] = {
            **motion,
            "torque": torque,
            "power": power,
            "inertia": np.asarray(inertia_rows),
            "coriolis": np.asarray(coriolis_rows),
            "gravity": np.asarray(gravity_rows),
        }
        summary[side] = {}

        for index, joint in enumerate(SHORT_JOINT_NAMES):
            summary[side][joint.lower()] = JointSummary(
                peak_abs_torque_nm=float(np.max(np.abs(torque[:, index]))),
                rms_torque_nm=float(np.sqrt(np.mean(torque[:, index] ** 2))),
                peak_abs_speed_rad_s=float(
                    np.max(np.abs(motion["qd"][:, index]))
                ),
                peak_abs_accel_rad_s2=float(
                    np.max(np.abs(motion["qdd"][:, index]))
                ),
                peak_abs_power_w=float(np.max(np.abs(power[:, index]))),
                rms_power_w=float(np.sqrt(np.mean(power[:, index] ** 2))),
            )

    return time, detailed, summary


def evaluate_support_case(
    user_mass: float,
    frame_mass: float,
    components: Sequence[RigidComponent],
    cop_distance: float,
    support_multiplier_per_leg: float,
) -> dict[str, np.ndarray | float]:
    """Evaluate the knee-dominant bent-knee support posture."""

    q = np.deg2rad(np.array([-60.0, -60.0, 120.0]))
    vertical_force = (
        support_multiplier_per_leg
        * (user_mass + frame_mass)
        * G_ACCEL
    )
    values = inverse_dynamics(
        q=q,
        qd=np.zeros(3),
        qdd=np.zeros(3),
        components=components,
        foot_force_xy=(0.0, vertical_force),
        cop_distance=cop_distance,
    )
    values["q"] = q
    values["vertical_force_n"] = vertical_force
    values["cop_distance_m"] = cop_distance
    return values


def round_up(value: float, increment: float) -> float:
    return math.ceil(value / increment) * increment


def select_motor_ratings(
    support_torque: Sequence[float],
    gait_summary: dict[str, dict[str, JointSummary]],
    engineering_factor: float,
) -> list[MotorRating]:
    """Map factored output torque to conservative motor-side targets."""

    peak_speeds = {
        joint: max(
            gait_summary["left"][joint].peak_abs_speed_rad_s,
            gait_summary["right"][joint].peak_abs_speed_rad_s,
        )
        for joint in ("knee", "ankle")
    }
    factored = np.abs(np.asarray(support_torque, dtype=float)) * engineering_factor

    ratings: list[MotorRating] = []
    for joint, index in (("knee", 1), ("ankle", 2)):
        # 20 N m increments retain margin and produce transparent selections:
        # 106.1 -> 120 N m knee; 42.5 -> 60 N m ankle.
        peak_output = round_up(float(factored[index]), 20.0)
        continuous_output = 0.5 * peak_output
        ratio = DEFAULT_REDUCTION_RATIOS[joint]
        efficiency = DEFAULT_GEAR_EFFICIENCY[joint]
        peak_motor = peak_output / (ratio * efficiency)
        continuous_motor = continuous_output / (ratio * efficiency)
        peak_speed = peak_speeds[joint]
        motor_rpm = peak_speed * ratio * 60.0 / (2.0 * math.pi)
        ratings.append(
            MotorRating(
                joint=joint.title(),
                continuous_output_nm=continuous_output,
                peak_output_nm=peak_output,
                reduction_ratio=ratio,
                efficiency=efficiency,
                continuous_motor_nm=continuous_motor,
                peak_motor_nm=peak_motor,
                measured_peak_joint_speed_rad_s=peak_speed,
                measured_peak_motor_rpm=motor_rpm,
            )
        )

    return ratings


def write_gait_csv(
    output_path: Path,
    time: np.ndarray,
    gait_detail: dict[str, dict[str, np.ndarray]],
) -> None:
    output_path.parent.mkdir(parents=True, exist_ok=True)
    headers = [
        "time_s",
        "side",
        "hip_angle_deg",
        "knee_angle_deg",
        "ankle_angle_deg",
        "hip_speed_rad_s",
        "knee_speed_rad_s",
        "ankle_speed_rad_s",
        "hip_accel_rad_s2",
        "knee_accel_rad_s2",
        "ankle_accel_rad_s2",
        "hip_reaction_nm",
        "knee_motor_nm",
        "ankle_motor_nm",
        "hip_power_w",
        "knee_power_w",
        "ankle_power_w",
    ]

    with output_path.open("w", newline="", encoding="utf-8") as stream:
        writer = csv.writer(stream)
        writer.writerow(headers)
        for side, values in gait_detail.items():
            for row, time_value in enumerate(time):
                writer.writerow(
                    [
                        f"{time_value:.6f}",
                        side,
                        *[f"{value:.6f}" for value in np.rad2deg(values["q"][row])],
                        *[f"{value:.6f}" for value in values["qd"][row]],
                        *[f"{value:.6f}" for value in values["qdd"][row]],
                        *[f"{value:.6f}" for value in values["torque"][row]],
                        *[f"{value:.6f}" for value in values["power"][row]],
                    ]
                )


def plot_gait_torques(
    output_path: Path,
    time: np.ndarray,
    gait_detail: dict[str, dict[str, np.ndarray]],
) -> None:
    output_path.parent.mkdir(parents=True, exist_ok=True)
    colors = {"left": "#1565C0", "right": "#E65100"}
    fig, axes = plt.subplots(2, 1, figsize=(10.0, 6.4), sharex=True)

    for side, values in gait_detail.items():
        axes[0].plot(
            time,
            values["torque"][:, 1],
            label=f"{side.title()} knee",
            color=colors[side],
            linewidth=2.1,
        )
        axes[1].plot(
            time,
            values["torque"][:, 2],
            label=f"{side.title()} ankle",
            color=colors[side],
            linewidth=2.1,
        )

    axes[0].set_title("Euler-Lagrange swing torque from the 2.4 s CAD gait")
    axes[0].set_ylabel("Knee torque [N m]")
    axes[1].set_ylabel("Ankle torque [N m]")
    axes[1].set_xlabel("Time [s]")
    for axis in axes:
        axis.axhline(0.0, color="#263238", linewidth=0.8)
        axis.grid(True, color="#CFD8DC", linewidth=0.7, alpha=0.8)
        axis.legend(frameon=False, ncol=2, loc="upper right")
        axis.spines[["top", "right"]].set_visible(False)
    fig.tight_layout()
    fig.savefig(output_path, dpi=180, bbox_inches="tight")
    plt.close(fig)
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
